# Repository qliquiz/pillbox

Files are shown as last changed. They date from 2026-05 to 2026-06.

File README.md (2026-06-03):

# PillBox IoT 💊 — Умная таблетница на базе ESP32-C3

Инновационное IoT-устройство для контроля регулярности приема лекарств. Таблетница автоматически напоминает о
необходимости приема звуковым сигналом, отправляет уведомления в Telegram и позволяет удаленно настраивать расписание
через чат-бота.

Проект разработан с учетом сетевых ограничений (работает в РФ без VPN через Google-прокси шлюз), но основные функции
напоминания теперь не зависят от интернета: время хранится в RTC-модуле DS1302. Текущая версия рассчитана на работу
от кабельного питания; аккумулятор и зарядный модуль описаны как аппаратный задел для следующего этапа.

---

## 🚀 Основные возможности

* **Локальная настройка (Captive Portal):** При первом запуске устройство создает собственную Wi-Fi сеть
  `PillBox_Setup`. Настройка параметров Wi-Fi, Chat ID, текущего времени RTC и расписания происходит в локальном
  веб-интерфейсе.
* **Автономное время:** Модуль DS1302 с батарейкой CR2032 хранит реальное время без запросов к NTP и продолжает идти
  при отключении основного питания.
* **Уведомления в Telegram:** Устройство присылает сообщение `🔔 ВРЕМЯ ПИТЬ ТАБЛЕТКИ!`, а также отчет
  `✅ Таблетки приняты`, когда вы открываете крышку. Уведомления отправляются при доступном Wi-Fi.
* **Удаленное управление:** Возможность менять время будильников прямо из чата Telegram с помощью команд `/t1 HH:MM` и
  `/t2 HH:MM`, а также корректировать RTC командой `/time YYYY-MM-DD HH:MM`.
* **Звуковой сигнал:** Пищалка подключена к `GPIO 5` и `GND`; прошивка генерирует звуковой тон функцией `tone()`, поэтому
  сигнал звучит как писк, а не как одиночные щелчки.
* **Энергонезависимая память:** Все настройки (Wi-Fi, будильники, Chat ID) сохраняются во встроенную память ESP32 (
  `Preferences`) и не стираются при отключении питания.
* **Питание:** Текущая прошивка рассчитана на стабильную работу от кабельного питания. Батарея и TP4056 будут
  использоваться для автономности на следующем этапе.
* **Мгновенный сброс:** Физический датчик на крышке мгновенно отключает пищалку при открытии, не дожидаясь окончания
  отправки сетевых запросов.

---

## 🔌 Схема подключения (Hardware)

Устройство спроектировано на базе микроконтроллера **ESP32-C3 Mini**.

| Компонент | Пин на ESP32-C3 | Описание подключения |
|:---|:---|:---|
| **Датчик крышки (кнопка)** | `GPIO 0` | Один контакт кнопки к `GPIO 0`, второй к `GND`. В прошивке включена внутренняя подтяжка `INPUT_PULLUP`. |
| **DS1302 RST / CE** | `GPIO 1` | Линия сброса/выбора RTC-модуля. |
| **Измерение батареи / зарядки** | `GPIO 2` | Зарезервировано для следующего этапа. В текущей прошивке не используется. |
| **DS1302 DAT / IO** | `GPIO 3` | Двунаправленная линия данных RTC-модуля. |
| **DS1302 CLK / SCLK** | `GPIO 4` | Тактовая линия RTC-модуля. |
| **Пищалка / звуковой излучатель** | `GPIO 5`, `GND` | Один контакт к `GPIO 5`, второй к `GND`. Прошивка генерирует тон 2500 Гц через `tone()`. Для громкого 5 В излучателя лучше использовать транзисторный ключ. |
| **DS1302 питание** | `3.3V`, `GND` | Основное питание RTC от ESP32, резервное питание от CR2032 на модуле часов. |
| **Зарядный модуль TP4056** | Питание | Аппаратный задел под автономность. Для текущей проверки от кабеля прошивка не использует сигналы зарядки или напряжение батареи. |

### Логика работы датчика крышки:

* **Крышка ЗАКРЫТА (кнопка нажата):** GPIO 0 замкнут на землю. На пине уровень **LOW (0)**.
* **Крышка ОТКРЫТА (кнопка отпущена):** Внутренняя подтяжка ESP32 удерживает пин в уровне **HIGH (1)**.

---

## 🛠 Инструкция по развертыванию (Setup Guide)

### Шаг 1: Подготовка Telegram-бота

1. Найдите в Telegram бота `@BotFather` и создайте нового бота с помощью команды `/newbot`. Скопируйте полученный *
   *Token**.
2. Найдите бота `@myidbot` и отправьте команду `/getid`, чтобы узнать ваш числовой **Chat ID**. Ник вида
   `@username` не подходит.
3. Отправьте вашему созданному боту команду `/start`, чтобы разрешить ему писать вам.

### Шаг 2: Настройка Google Apps Script (Прокси-шлюз)

Для стабильной отправки сообщений из РФ используется бесплатный веб-интерфейс Google в качестве моста:

1. Перейдите на [script.google.com](https://script.google.com/) и создайте новый проект.
2. Вставьте следующий код:
   ```javascript
   function doGet(e) {
     var token = e.parameter.token;
     var method = e.parameter.method || "sendMessage";
     var url = "https://api.telegram.org/bot" + token + "/" + method;
     
     var params = [];
     for (var p in e.parameter) {
       if (p !== 'token' && p !== 'method') {
         params.push(p + "=" + encodeURIComponent(e.parameter[p]));
       }
     }
     params.push("nocache=" + Math.random());
     if (params.length > 0) url += "?" + params.join("&");
     
     var response = UrlFetchApp.fetch(url, {muteHttpExceptions: true});
     return ContentService.createTextOutput(response.getContentText());
   }
   ```
3. Нажмите **«Начать развертывание»** -> **«Новое развертывание»**.
4. Выберите тип: **«Веб-приложение»**. Доступ: **«Все» (Anyone)**.
5. Скопируйте полученный URL (он понадобится для прошивки).

### Шаг 3: Настройка проекта в IDE (PlatformIO)

1. Откройте проект в CLion / VS Code с установленным плагином PlatformIO.
2. Приведите файл `platformio.ini` к следующему виду:
   ```ini
   [env:esp32-c3-devkitm-1]
   platform = espressif32
   board = esp32-c3-devkitm-1
   framework = arduino
   monitor_speed = 115200
   build_flags = 
       -D ARDUINO_USB_MODE=1
       -D ARDUINO_USB_CDC_ON_BOOT=1
   lib_deps = 
       bblanchon/ArduinoJson @ ^6.21.3
       makuna/RTC @ ^2.5.0
   ```
3. В файле `src/main.cpp` найдите блок констант и вставьте ваши данные:
   ```cpp
   const String BOT_TOKEN = "ВАШ_ТОКЕН_ОТ_BOTFATHER";
   const String G_SCRIPT_URL = "ВАШ_URL_ОТ_GOOGLE_SCRIPT";
   ```
4. Загрузите прошивку в плату.

---

## 📱 Первый запуск и настройка

1. Зайти в Телеграм-бота @IoTRegApiBot и нажать "Старт" (/start).
2. Подайте питание на таблетницу.
3. С телефона подключитесь к появившейся Wi-Fi сети `PillBox_Setup` (пароль не требуется).
4. В открывшемся окне авторизации (или перейдя по адресу `192.168.4.1`) введите:
    * **Имя Wi-Fi:** Название точки доступа вашего телефона (или домашнего роутера).
    * **Пароль Wi-Fi:** Пароль от этой сети.
    * **Chat ID:** Ваш числовой Telegram ID (полученный на Шаге 1, не ник).
    * **Текущее время:** Локальное время телефона для первичной настройки DS1302.
    * **Утро / Вечер:** Желаемое время напоминаний.
5. Нажмите **«Сохранить»**. Устройство запишет настройки и время в RTC, затем перезагрузится.
6. Если Wi-Fi доступен, устройство подключится к сети и пришлет в Telegram сообщение: `Таблетница в сети! 🟢`.
   Если сохраненная сеть недоступна, устройство поднимет `PillBox_Setup`, чтобы параметры можно было ввести заново.
   Будильники при этом продолжают проверяться по DS1302.

### Сброс сохраненных настроек

Если нужно заново открыть портал настройки и стереть сохраненные Wi-Fi, Chat ID и расписание, выполните:

```bash
/opt/homebrew/bin/pio run -t erase -e esp32-c3-devkitm-1
/opt/homebrew/bin/pio run -t upload -e esp32-c3-devkitm-1
```

Команда `erase` стирает Flash-память ESP32, но не сбрасывает DS1302: часы продолжают идти от своей батарейки CR2032.

---

## 🤖 Управление через Telegram

Вы можете отправлять боту следующие команды:

* `/status` — Возвращает текущее системное время таблетницы, расписание будильников и физическое состояние крышки (
  открыта/закрыта).
* `/t1 HH:MM` — Изменить время утреннего приема (например, `/t1 08:30`).
* `/t2 HH:MM` — Изменить время вечернего приема (например, `/t2 21:15`).
* `/time YYYY-MM-DD HH:MM` — Установить текущее время RTC (например, `/time 2026-06-01 21:30`).

---

## 🛠 Технологический стек

* **Платформа:** ESP32-C3 (RISC-V 32-bit CPU, Wi-Fi & Bluetooth).
* **Среда разработки:** CLion / VS Code + PlatformIO.
* **Фреймворк:** Arduino (C++).
* **Многозадачность:** FreeRTOS (управление пищалкой выделено в отдельную низкоуровневую задачу для стабильной работы
  звука).
* **Звук:** Arduino `tone()` на `GPIO 5`, частота сигнала 2500 Гц.
* **RTC:** DS1302 с резервной батарейкой CR2032.
* **Питание:** Кабельное питание. Аккумулятор и зарядный модуль TP4056 подготовлены для следующего этапа.
* **Сетевые протоколы:** HTTPS, DNS (для Captive Portal).
* **Облачные технологии:** Google Apps Script (проксирование трафика).

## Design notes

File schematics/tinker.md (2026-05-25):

# Tinkercad
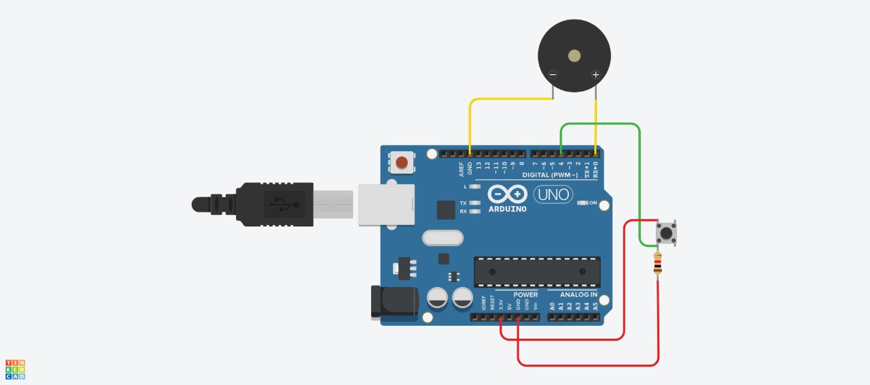
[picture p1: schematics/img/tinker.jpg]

🔗 [Ссылка](https://www.tinkercad.com/things/cp1gPXaVb1g-powerful-kup-jaagub)

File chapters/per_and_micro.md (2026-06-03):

### Раздел 2. Способы взаимодействия периферийного оборудования и микроконтроллера

В разработанном устройстве реализовано три уровня взаимодействия:
локальное (физическое подключение датчиков и актуаторов к портам ввода-вывода микроконтроллера)
аппаратное хранение времени и сетевое (передача данных через беспроводные интерфейсы).

#### 2.1. Локальное взаимодействие с периферией

Для контроля состояния устройства и генерации оповещений используются дискретные цифровые
каналы ввода-вывода общего назначения (GPIO) микроконтроллера ESP32-C3.

1. **Цифровой вход — Датчик положения крышки (GPIO 0)**
   Для опроса состояния крышки используется кнопка, подключенная между портом GPIO 0 и землей (GND).
   В программе включена внутренняя подтяжка `INPUT_PULLUP`.
    * При закрытой крышке кнопка нажата, цепь замкнута на землю, и на входе микроконтроллера фиксируется
      низкий логический уровень (`LOW`).
    * При открытии крышки цепь размыкается, и внутренняя подтяжка удерживает вывод в высоком уровне (`HIGH`).
      Данный переход обрабатывается управляющей программой как сигнал к отключению будильника.

2. **Цифровой выход — звуковой излучатель (GPIO 5)**
   Для звукового оповещения используется пищалка, подключенная между GPIO 5 и общей землей (GND).
   Управляющая программа генерирует на выводе звуковой сигнал частотой 2500 Гц с помощью функции `tone()`.
   Такой режим подходит для пассивного излучателя и дает более выраженный писк, чем простое включение уровня `HIGH`.
   Если требуется питание излучателя от линии 5 В или большая громкость, рекомендуется использовать транзисторный ключ,
   чтобы не перегружать вывод ESP32-C3.

3. **Часы реального времени DS1302**
   Для автономного подсчета времени используется RTC-модуль DS1302 с резервной батарейкой CR2032.
   Модуль подключается к ESP32-C3 по трехпроводному интерфейсу:
    * `RST` / `CE` -> GPIO 1;
    * `DAT` / `IO` -> GPIO 3;
    * `CLK` / `SCLK` -> GPIO 4;
    * `VCC` -> 3.3 В, `GND` -> общая земля.
      После первичной настройки модуль продолжает хранить текущее время независимо от Wi-Fi и основного питания.

4. **Резервный вход питания (GPIO 2)**
   GPIO 2 зарезервирован для следующего этапа — измерения напряжения батареи или состояния зарядки.
   В текущей прошивке этот вход не используется.

5. **Зарядный модуль TP4056**
   Зарядный модуль и аккумулятор рассматриваются как аппаратный задел под автономность. На текущем этапе устройство
   проверяется от кабельного питания, а прошивка не рассчитывает заряд и не принимает решений по состоянию батареи.

6. **Проводной интерфейс UART**
   Обмен данными между микроконтроллером и персональным компьютером на этапе разработки,
   прошивки и отладки осуществляется по последовательному интерфейсу UART через встроенный
   в чип ESP32-C3 аппаратный USB-CDC конвертер.

#### 2.2. Сетевое взаимодействие и протоколы связи

Сетевая часть устройства построена на базе встроенного приемопередатчика
Wi-Fi и стека протоколов TCP/IP.

1. **Режимы работы Wi-Fi:**
    * **Режим AP (Точка доступа):** Активируется при первом запуске или отсутствии сохраненных сетевых настроек.
      Микроконтроллер создает локальную сеть `PillBox_Setup` для подключения смартфона пользователя.
    * **Режим STA (Клиент):** Рабочий режим, в котором устройство подключается к беспроводной точке
      доступа для выхода в глобальную сеть Интернет.
    * **Режим повторной настройки:** Если сохраненная сеть временно недоступна, устройство не стирает настройки
      автоматически, а поднимает `PillBox_Setup`, чтобы пользователь мог изменить Wi-Fi, Chat ID и расписание.
      Проверка расписания по DS1302 при этом продолжает выполняться.

2. **Протоколы прикладного уровня:**
    * **HTTP:** Используется в режиме точки доступа. На микроконтроллере развернут легковесный веб-сервер,
      который отдает конфигурационную HTML-страницу пользователю и принимает новые параметры расписания и сети через
      GET-запросы (`/save?s=...&p=...`).
    * **DNS:** Задействован в режиме настройки для реализации технологии Captive Portal.
      Локальный DNS-сервер перехватывает все системные запросы подключившегося смартфона и принудительно перенаправляет
      их на веб-интерфейс таблетницы (`192.168.4.1`), вызывая автоматическое появление окна настройки на экране
      телефона.
    * **HTTPS:** Применяется для безопасной отправки уведомлений и получения команд.
      Поскольку прямое обращение к серверам Telegram API (`api.telegram.org`) с микроконтроллеров на территории
      РФ заблокировано или нестабильно, запросы отправляются методом GET по защищенному каналу на облачный прокси-сервер
      Google Apps Script,
      находящийся вне зоны ограничений, который выступает шлюзом для ретрансляции данных в Telegram.

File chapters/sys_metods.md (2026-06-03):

### Раздел 3. Способы взаимодействия модулей системы

Разработанная система представляет собой распределенный аппаратно-программный комплекс,
состоящий из шести основных взаимодействующих модулей:

1. **Аппаратный модуль (микроконтроллер ESP32-C3)** — конечное устройство с датчиками.
2. **Пользовательское устройство (смартфон)** — средство локальной настройки и отображения интерфейса.
3. **Модуль часов реального времени DS1302** — автономный источник текущего времени.
4. **Подсистема питания** — на текущем этапе работа от кабельного питания; аккумулятор и TP4056 подготовлены для
   следующего этапа.
5. **Облачный прокси-сервер (Google Apps Script)** — шлюз для обхода сетевых ограничений.
6. **Сервер обмена сообщениями (Telegram Bot API)** — среда удаленного управления и оповещения.

Взаимодействие между данными модулями построено на базе различных программных интерфейсов и протоколов передачи данных.
Архитектуру взаимодействия можно разделить на три ключевых сценария.

#### 3.1. Локальное взаимодействие: Смартфон ↔ ESP32-C3 (Этап настройки)

На этапе первоначальной конфигурации при отсутствии подключения к сети Интернет
взаимодействие модулей осуществляется напрямую без участия сторонних серверов.

* **Используемый интерфейс:** Локальный HTTP API.
* **Механизм взаимодействия:**
  Смартфон пользователя подключается к Wi-Fi сети микроконтроллера.
  При попытке любого сетевого запроса срабатывает встроенный DNS-перехватчик,
  перенаправляющий пользователя на веб-страницу настройки, хранящуюся в постоянной памяти ESP32-C3.
  Передача параметров осуществляется посредством отправки асинхронного HTTP-запроса методом `GET`
  с параметрами в строке запроса:
  `GET /save?s=[SSID]&p=[password]&c=[Chat_ID]&dt=[YYYY-MM-DDTHH:MM]&t1=[HH:MM]&t2=[HH:MM]`
  Микроконтроллер парсит строку запроса, сохраняет полученные данные в энергонезависимую память
  записывает текущее время в DS1302 и выполняет перезагрузку для перехода в рабочий режим.

#### 3.2. Локальное аппаратное взаимодействие: ESP32-C3 ↔ DS1302

Для проверки расписания таблетница использует аппаратные часы реального времени DS1302.

* **Используемый интерфейс:** Трехпроводной последовательный интерфейс DS1302.
* **Механизм взаимодействия:**
  Микроконтроллер обращается к DS1302 по линиям `RST`, `DAT` и `CLK`, считывает текущие часы и минуты
  и сравнивает их с сохраненным расписанием. Благодаря резервной батарейке CR2032 часы продолжают идти без
  подключения к интернету и без основного питания устройства.

#### 3.3. Исходящее взаимодействие: ESP32-C3 → Google Cloud → Telegram

Для отправки уведомлений конечное устройство должно передать данные на серверы Telegram.
Из-за блокировок прямого доступа к API Telegram на территории РФ используется промежуточный облачный шлюз.

* **Используемый интерфейс:** Web API с проксированием.
* **Механизм взаимодействия:**
  ESP32-C3 формирует защищенное HTTPS-соединение с сервером Google Apps Script,
  передавая параметры сообщения в зашифрованном GET-запросе:
  `GET /macros/s/[Script_ID]/exec?token=[Bot_Token]&method=sendMessage&chat_id=[Chat_ID]&text=[Message]`
  Облачный скрипт Google принимает этот запрос, декодирует параметры и инициирует
  внутренний запрос со стороны серверов Google к официальному серверу Telegram:
  `POST https://api.telegram.org/bot[Bot_Token]/sendMessage`
  Telegram доставляет push-уведомление на смартфон пользователя в чат-бот.

#### 3.4. Входящее взаимодействие: Смартфон → Telegram → Google Cloud → ESP32-C3

Для удаленного изменения времени будильников, корректировки RTC или запроса статуса устройства пользователь
отправляет текстовые команды в чат-бот на своем смартфоне.

* **Используемый интерфейс:** Web API Telegram.
* **Механизм взаимодействия:**
    1. Команда пользователя поступает на серверы Telegram и сохраняется в очереди сообщений бота.
    2. Микроконтроллер ESP32-C3, находясь в рабочем режиме, каждые 7 секунд отправляет через Google-шлюз запрос на
       получение обновлений:
       `GET /exec?token=[Bot_Token]&method=getUpdates&offset=[Last_Update_ID+1]`
    3. Google-шлюз транслирует этот запрос в Telegram, получает массив новых сообщений в формате JSON и пересылает его
       обратно на ESP32-C3.
    4. Микроконтроллер разбирает полученный JSON-пакет с помощью библиотеки `ArduinoJson`.
       Если ID отправителя совпадает с сохраненным в памяти `Chat_ID`, устройство извлекает текст команды.
       Команды `/t1` и `/t2` обновляют расписание в оперативной памяти и Flash-памяти, команда `/time`
       записывает текущее время в DS1302, а команда `/status` возвращает текущее состояние часов и крышки.
       Для корректной доставки кириллицы и служебных символов текст Telegram-сообщений URL-кодируется перед отправкой
       на Google Apps Script.

#### 3.5. Питание и режим без Wi-Fi

На текущем этапе устройство проверяется от кабельного питания. При недоступном Wi-Fi прошивка поднимает локальный портал
`PillBox_Setup` для повторной настройки, а проверка расписания продолжает работать от DS1302. Аккумулятор и TP4056
будут задействованы в прошивке на следующем этапе.

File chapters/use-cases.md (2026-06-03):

### Раздел 7. Сценарии использования и реакция устройства

Для описания взаимодействия пользователя с умной таблетницей разработаны
три основных сценария использования. В каждом сценарии предусмотрена визуальная,
звуковая или текстовая обратная связь от устройства, чтобы пользователь был уверен в правильности своих действий.

#### 7.1. Сценарий 1: Первоначальная настройка устройства

* **Действующее лицо:** Пользователь.
* **Предусловие:** Таблетница включена впервые от кабельного питания. В памяти устройства отсутствуют
  данные Wi-Fi и требуется первичная установка времени RTC.
  Пользователь нажал /start в @IoTRegApiBot
* **Основной сценарий взаимодействия:**
    1. Пользователь включает устройство от кабельного питания.
    2. Пользователь открывает настройки Wi-Fi на своем смартфоне и видит новую точку доступа с именем `PillBox_Setup`.
    3. Пользователь подключается к этой сети. На экране смартфона автоматически всплывает окно настройки с полями ввода.
    4. Пользователь заполняет поля: имя и пароль Wi-Fi, свой числовой Telegram Chat ID, текущее время и желаемое время
       приемов.
    5. Пользователь нажимает кнопку **«СОХРАНИТЬ»** на веб-странице.
* **Реакция устройства:**
    * После нажатия кнопки веб-интерфейс отображает надпись **«Готово!»**.
    * Через 2 секунды устройство выполняет автоматическую перезагрузку.
    * Устройство записывает текущее время в DS1302, сохраняет настройки и перезагружается.
    * При успешном подключении к мобильному хотспоту устройство отправляет пользователю в Telegram приветственное
      сообщение: **«Таблетница в сети! 🟢»**.
    * Если сохраненная сеть временно недоступна, устройство поднимает `PillBox_Setup` для повторной настройки.
      Будильники при этом продолжают работать по DS1302, но Telegram-уведомления и команды недоступны до восстановления
      Wi-Fi.

#### 7.2. Сценарий 2: Срабатывание будильника и прием лекарств

* **Действующее лицо:** Пользователь.
* **Предусловие:** Время на DS1302 настроено, расписание сохранено,
  крышка таблетницы закрыта.
* **Основной сценарий взаимодействия:**
    1. Внутреннее время таблетницы совпадает с временем будильника.
    2. Устройство начинает генерировать сигнал тревоги.
    3. Пользователь подходит к устройству, открывает общую крышку таблетницы, берет необходимый пенал с лекарствами и
       закрывает крышку обратно.
* **Реакция устройства:**
    * **В момент срабатывания:** Пищалка на GPIO 5 начинает издавать прерывистый тон. Если Wi-Fi доступен, в Telegram
      пользователю приходит push-уведомление: **«🔔 ВРЕМЯ ПИТЬ ТАБЛЕТКИ!»**.
    * **В момент открытия крышки:** Как только крышка приоткрывается, датчик фиксирует уровень `HIGH`, и зуммер
      мгновенно
      замолкает.
    * **После открытия:** При доступном Wi-Fi в Telegram приходит подтверждающее сообщение:
      **«✅ Таблетки приняты.»**.

#### 7.3. Сценарий 3: Удаленное управление и мониторинг

* **Действующее лицо:** Пользователь.
* **Предусловие:** Устройство находится в рабочем режиме и подключено к мобильной точке доступа.
* **Основной сценарий взаимодействия:**
    1. Пользователь, находясь вне дома, открывает чат-бот таблетницы в Telegram.
    2. Пользователь отправляет команду для изменения расписания (например, `/t1 09:30`), команду установки RTC
       (`/time 2026-06-01 21:30`) или команду запроса текущего состояния (`/status`).
* **Реакция устройства:**
    * При получении команды настройки времени (`/t1` или `/t2`) устройство обрабатывает запрос, сохраняет его в память
      NVS и отправляет ответное сообщение: **«✅ Утро установлено: 09:30»**.
    * При получении команды `/time` устройство записывает новое текущее время в DS1302.
    * При получении команды `/status` устройство мгновенно опрашивает свои датчики и RTC-модуль и присылает
      подробную сводку:
        * `📊 СТАТУС:`
        * `🕒 RTC: 2026-06-01 13:45:35` (позволяет пользователю убедиться, что часы идут верно).
        * `🌅 Утро: 09:30`
        * `🌌 Вечер: 20:00`
        * `📦 Крышка: ЗАКРЫТА` (позволяет удаленно проверить, не забыли ли закрыть таблетницу дома).

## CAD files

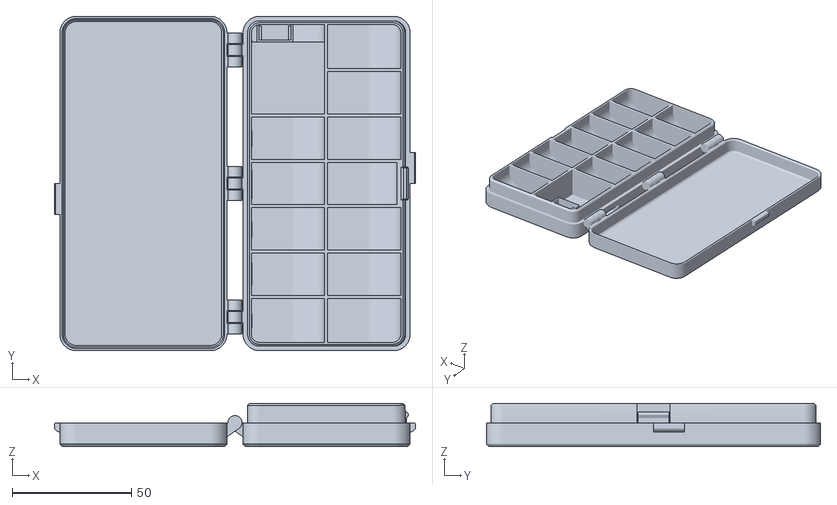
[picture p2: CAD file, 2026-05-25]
3d_models/pillbox.stl
151.1 x 140.0 x 18.0

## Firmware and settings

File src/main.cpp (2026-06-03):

#include <Arduino.h>
#include <ArduinoJson.h>
#include <DNSServer.h>
#include <HTTPClient.h>
#include <Preferences.h>
#include <RtcDS1302.h>
#include <ThreeWire.h>
#include <WebServer.h>
#include <WiFi.h>
#include <WiFiClientSecure.h>


const String BOT_TOKEN = "";
const String G_SCRIPT_URL = "";

constexpr int LID_SENSOR_PIN = 0;
constexpr int RTC_RST_PIN = 1;
constexpr int RTC_DAT_PIN = 3;
constexpr int RTC_CLK_PIN = 4;
constexpr int BUZZER_PIN = 5;
constexpr int BUZZER_TONE_HZ = 2500;
constexpr unsigned long WIFI_RETRY_INTERVAL_MS = 5UL * 60UL * 1000UL;
constexpr unsigned long WIFI_RETRY_TIMEOUT_MS = 15000UL;

String ssid, pass, chatId, alarm1, alarm2;
String lastTriggeredMinute = "";
bool wifiReconnectInProgress = false;
volatile bool isAlerting = false;
unsigned long lastWiFiRetry = 0;
unsigned long wifiRetryStartedAt = 0;
long lastUpdateId = 0; // ID последнего обработанного сообщения из Telegram

ThreeWire rtcWire(RTC_DAT_PIN, RTC_CLK_PIN, RTC_RST_PIN); // DS1302: DAT/IO, CLK/SCLK, RST/CE
RtcDS1302<ThreeWire> rtc(rtcWire);
Preferences prefs; // объект для работы с энергонезависимой памятью (Flash)
DNSServer dnsServer; // DNS-сервер для перехвата запросов (Captive Portal)
WebServer server(80); // локальный веб-сервер для настройки таблетницы по Wi-Fi
QueueHandle_t msgQueue; // очередь для безопасной передачи сообщений между задачами

// ======================= ВРЕМЯ И ДАТЧИКИ =======================

bool isLidClosed()
{
	// Кнопка крышки замыкает GPIO0 на GND, поэтому используем INPUT_PULLUP.
	return digitalRead(LID_SENSOR_PIN) == LOW;
}

String twoDigits(const uint8_t value)
{
	if (value < 10) return "0" + String(value);
	return String(value);
}

String formatRtcTime(const RtcDateTime &dt)
{
	return twoDigits(dt.Hour()) + ":" + twoDigits(dt.Minute());
}

String formatRtcDateTime(const RtcDateTime &dt)
{
	if (!dt.IsValid() || dt.Year() < 2024) return "не настроено";

	return String(dt.Year()) + "-" + twoDigits(dt.Month()) + "-" + twoDigits(dt.Day()) + " " +
	       twoDigits(dt.Hour()) + ":" + twoDigits(dt.Minute()) + ":" + twoDigits(dt.Second());
}

bool parseDateTime(const String &value, RtcDateTime &result)
{
	if (value.length() < 16) return false;
	if (value.charAt(4) != '-' || value.charAt(7) != '-' || value.charAt(13) != ':') return false;

	const char separator = value.charAt(10);
	if (separator != 'T' && separator != ' ') return false;

	const uint16_t year = value.substring(0, 4).toInt();
	const uint8_t month = value.substring(5, 7).toInt();
	const uint8_t day = value.substring(8, 10).toInt();
	const uint8_t hour = value.substring(11, 13).toInt();
	const uint8_t minute = value.substring(14, 16).toInt();

	if (year < 2024 || month < 1 || month > 12 || day < 1 || day > 31 || hour > 23 || minute > 59)
	{
		return false;
	}

	result = RtcDateTime(year, month, day, hour, minute, 0);
	return result.IsValid();
}

bool isValidAlarmTime(const String &value)
{
	if (value.length() != 5 || value.charAt(2) != ':') return false;
	const int hour = value.substring(0, 2).toInt();
	const int minute = value.substring(3, 5).toInt();
	return hour >= 0 && hour <= 23 && minute >= 0 && minute <= 59;
}

void setRtcDateTime(const RtcDateTime &dt)
{
	if (rtc.GetIsWriteProtected()) rtc.SetIsWriteProtected(false);
	if (!rtc.GetIsRunning()) rtc.SetIsRunning(true);
	rtc.SetDateTime(dt);
}

// ======================= TELEGRAM =======================

String urlEncode(const String &value)
{
	String encoded = "";
	for (size_t i = 0; i < value.length(); i++)
	{
		const auto c = static_cast<uint8_t>(value.charAt(i));
		if ((c >= 'A' && c <= 'Z') || (c >= 'a' && c <= 'z') || (c >= '0' && c <= '9') ||
		    c == '-' || c == '_' || c == '.' || c == '~')
		{
			encoded += static_cast<char>(c);
		}
		else if (c == ' ')
		{
			encoded += "%20";
		}
		else
		{
			const auto hex = "0123456789ABCDEF";
			encoded += '%';
			encoded += hex[c >> 4];
			encoded += hex[c & 0x0F];
		}
	}
	return encoded;
}

// Функция для добавления сообщения в очередь на отправку (не блокирует процессор)
void sendMsg(const String &text)
{
	// Выделяем память под строку и копируем её, чтобы данные не пропали, пока задача их не заберет
	char *msg = strdup(text.c_str());
	// Пытаемся отправить указатель на строку в очередь без ожидания (0 миллисекунд)
	if (xQueueSend(msgQueue, &msg, 0) != pdPASS)
	{
		free(msg); // если очередь переполнена, удаляем сообщение, чтобы не засорять память
	}
}

void startWiFiReconnect()
{
	if (ssid == "" || WiFiClass::getMode() == WIFI_AP) return;

	WiFiClass::mode(WIFI_STA);
	WiFi.begin(ssid.c_str(), pass.c_str());
	wifiReconnectInProgress = true;
	wifiRetryStartedAt = millis();
	lastWiFiRetry = millis();
	Serial.println("Пробуем восстановить WiFi.");
}

void serviceWiFiReconnect()
{
	if (WiFiClass::getMode() == WIFI_AP || ssid == "") return;

	if (WiFiClass::status() == WL_CONNECTED)
	{
		if (wifiReconnectInProgress)
		{
			wifiReconnectInProgress = false;
			sendMsg("Таблетница снова в сети! 🟢");
		}
		return;
	}

	if (wifiReconnectInProgress)
	{
		if (millis() - wifiRetryStartedAt > WIFI_RETRY_TIMEOUT_MS)
		{
			wifiReconnectInProgress = false;
			WiFi.disconnect(true);
			WiFiClass::mode(WIFI_OFF);
			Serial.println("WiFi не найден, остаемся в автономном режиме.");
		}
		return;
	}

	if (millis() - lastWiFiRetry > WIFI_RETRY_INTERVAL_MS)
	{
		startWiFiReconnect();
	}
}

// Функция для отправки любых запросов в Telegram через Google-прокси
String callTelegram(const String &method, const String &params)
{
	if (WiFiClass::status() != WL_CONNECTED)
	{
		Serial.println("Telegram skipped: WiFi is not connected.");
		return "";
	}
	if (BOT_TOKEN == "" || G_SCRIPT_URL == "")
	{
		Serial.println("Telegram skipped: BOT_TOKEN or G_SCRIPT_URL is empty.");
		return "";
	}

	WiFiClientSecure client;
	client.setInsecure(); // отключаем строгую проверку SSL-сертификатов Google (экономит память)

	HTTPClient http;
	String url = G_SCRIPT_URL + "?token=" + BOT_TOKEN + "&method=" + method + "&" + params;

	// Настраиваем правила HTTP-клиента
	http.setFollowRedirects(HTTPC_STRICT_FOLLOW_REDIRECTS);
	// Google всегда делает редирект, мы обязаны следовать за ним
	http.setTimeout(15000); // таймаут ожидания ответа от Google — 15 секунд

	String response = "";
	if (http.begin(client, url))
	{
		const int httpCode = http.GET();
		Serial.print("Telegram ");
		Serial.print(method);
		Serial.print(" HTTP ");
		Serial.println(httpCode);
		if (httpCode == 200) response = http.getString();
		if (response != "")
		{
			Serial.print("Telegram response: ");
			Serial.println(response.substring(0, 180));
		}
		http.end();
	}
	else
	{
		Serial.println("Telegram HTTP begin failed.");
	}
	return response;
}

// Фоновая задача отправки сообщений
[[noreturn]] void telegramTask(void *pvParameters)
{
	char *msgText;
	for (;;)
	{
		// Ждем появления сообщения в очереди. Если очередь пуста, задача "засыпает" и не тратит ресурсы процессора
		if (xQueueReceive(msgQueue, &msgText, portMAX_DELAY) == pdPASS)
		{
			if (chatId == "")
			{
				Serial.println("Telegram send skipped: Chat ID is empty.");
			}
			else
			{
				callTelegram("sendMessage", "chat_id=" + chatId + "&text=" + urlEncode(String(msgText)));
			}
			free(msgText); // освобождаем динамическую память, выделенную под текст
		}
	}
}

// Функция разбора входящих сообщений и команд из Telegram
void checkBot()
{
	String json = callTelegram("getUpdates", "offset=" + String(lastUpdateId + 1));
	if (json == "" || json.length() < 10) return;

	DynamicJsonDocument doc(2048); // создаем буфер для разбора JSON
	if (deserializeJson(doc, json)) return;

	const JsonArray results = doc["result"].as<JsonArray>();
	for (JsonObject result: results)
	{
		lastUpdateId = result["update_id"];

		auto text = result["message"]["text"].as<String>();
		auto fromId = result["message"]["chat"]["id"].as<String>();
		fromId.trim();
		chatId.trim();

		if (fromId == chatId)
		{
			if (text.startsWith("/t1 "))
			{
				const String newAlarm = text.substring(4, 9);
				if (isValidAlarmTime(newAlarm))
				{
					alarm1 = newAlarm;
					sendMsg("✅ Утро: " + alarm1);
				}
				else
				{
					sendMsg("⚠️ Формат: /t1 HH:MM");
				}
			}
			else if (text.startsWith("/t2 "))
			{
				const String newAlarm = text.substring(4, 9);
				if (isValidAlarmTime(newAlarm))
				{
					alarm2 = newAlarm;
					sendMsg("✅ Вечер: " + alarm2);
				}
				else
				{
					sendMsg("⚠️ Формат: /t2 HH:MM");
				}
			}
			else if (text.startsWith("/time "))
			{
				RtcDateTime newTime;
				if (parseDateTime(text.substring(6), newTime))
				{
					setRtcDateTime(newTime);
					sendMsg("✅ Время RTC: " + formatRtcDateTime(newTime));
				}
				else
				{
					sendMsg("⚠️ Формат: /time YYYY-MM-DD HH:MM");
				}
			}
			else if (text == "/status")
			{
				const RtcDateTime now = rtc.GetDateTime();
				String lid = isLidClosed() ? "ЗАКРЫТА" : "ОТКРЫТА";
				sendMsg(
					"📊 СТАТУС:\n🕒 RTC: " + formatRtcDateTime(now) + "\n🌅 Утро: " + alarm1 +
					"\n🌌 Вечер: " + alarm2 + "\n📦 Крышка: " + lid
				);
			}
			// Сохраняем новые будильники во Flash-память ESP32
			prefs.begin("pillbox", false);
			prefs.putString("t1", alarm1);
			prefs.putString("t2", alarm2);
			prefs.end();
		}
	}
}

// Фоновая задача для регулярного опроса Telegram
[[noreturn]] void botPollTask(void *pvParameters)
{
	for (;;)
	{
		if (WiFiClass::status() == WL_CONNECTED && WiFiClass::getMode() == WIFI_STA)
		{
			checkBot();
		}
		vTaskDelay(7000 / portTICK_PERIOD_MS); // спим ровно 7 секунд без задержки основного ядра
	}
}

// ======================= РАБОТА С ЖЕЛЕЗОМ =======================

void buzzerOn()
{
	tone(BUZZER_PIN, BUZZER_TONE_HZ);
}

void buzzerOff()
{
	noTone(BUZZER_PIN);
	digitalWrite(BUZZER_PIN, LOW);
}

// Фоновая задача для пищалки (приоритет 3)
[[noreturn]] void buzzerTask(void *pvParameters)
{
	for (;;)
	{
		if (isAlerting)
		{
			// ФАЗА ЗВУКА: пищим 300 мс, но проверяем флаг крышки каждые 10 мс для мгновенного сброса
			for (int i = 0; i < 30; i++)
			{
				if (!isAlerting) break; // если крышку открыли, мгновенно прерываем писк
				buzzerOn();
				vTaskDelay(10 / portTICK_PERIOD_MS);
			}
			buzzerOff();

			// ФАЗА ТИШИНЫ: ждем 800 мс, также регулярно опрашивая флаг крышки
			for (int i = 0; i < 80; i++)
			{
				if (!isAlerting) break;
				vTaskDelay(10 / portTICK_PERIOD_MS);
			}
		}
		else
		{
			// Если тревоги нет, гарантируем, что пищалка выключена, и "спим"
			buzzerOff();
			vTaskDelay(50 / portTICK_PERIOD_MS);
		}
	}
}

// HTML-сайт настройки (хранится в Flash-памяти программ PROGMEM)
constexpr char INDEX_HTML[] PROGMEM = R"=====(
<!DOCTYPE html><html><head><meta charset="utf-8"><meta name="viewport" content="width=device-width, initial-scale=1.0">
<style>body{font-family:sans-serif;background:#f4f4f9;padding:20px;display:flex;flex-direction:column;align-items:center;}
.card{background:white;padding:25px;border-radius:15px;box-shadow:0 4px 10px rgba(0,0,0,0.1);width:100%;max-width:320px;}
input{width:100%;padding:12px;margin-top:10px;border:1px solid #ddd;border-radius:8px;box-sizing:border-box;font-size:16px;}
button{width:100%;background:#4CAF50;color:white;border:none;padding:15px;border-radius:8px;margin-top:20px;width:100%;}</style></head>
<body><div class="card"><h2>PillBox Setup 💊</h2>
<input id="s" placeholder="Имя WiFi сети"><input type="password" id="p" placeholder="Пароль WiFi"><input id="c" placeholder="Chat ID">
<label>Текущее время:</label><input type="datetime-local" id="dt">
<label>Утро:</label><input type="time" id="t1" value="08:00"><label>Вечер:</label><input type="time" id="t2" value="20:00">
<button onclick="save()">СОХРАНИТЬ</button></div>
<script>
function pad(n){return String(n).padStart(2,'0')}
const d=new Date();document.getElementById('dt').value=`${d.getFullYear()}-${pad(d.getMonth()+1)}-${pad(d.getDate())}T${pad(d.getHours())}:${pad(d.getMinutes())}`;
function save(){
const q=new URLSearchParams({s:document.getElementById('s').value,p:document.getElementById('p').value,c:document.getElementById('c').value,dt:document.getElementById('dt').value,t1:document.getElementById('t1').value,t2:document.getElementById('t2').value});
fetch('/save?'+q.toString()).then(()=>alert("Настройки сохранены! Перезагрузка..."));
}</script></body></html>
)=====";

// Обработчик сохранения данных, прилетевших с веб-страницы телефона
void handleSave()
{
	prefs.begin("pillbox", false); // открываем память во Flash для записи
	prefs.putString("s", server.arg("s"));
	prefs.putString("p", server.arg("p"));
	prefs.putString("c", server.arg("c"));
	prefs.putString("t1", server.arg("t1"));
	prefs.putString("t2", server.arg("t2"));
	prefs.end();

	RtcDateTime setupTime;
	if (parseDateTime(server.arg("dt"), setupTime))
	{
		setRtcDateTime(setupTime);
	}

	server.send(200, "text/plain", "OK");
	delay(2000);
	ESP.restart(); // применяем
}

void startSetupPortal()
{
	WiFiClass::mode(WIFI_AP);
	WiFi.softAP("PillBox_Setup");
	dnsServer.start(53, "*", WiFi.softAPIP());
	server.on("/", []() {
		server.send(200, "text/html", INDEX_HTML);
	});
	server.on("/save", handleSave);
	server.onNotFound([]() {
		server.sendHeader("Location", "/", true);
		server.send(302, "text/plain", "");
	});
	server.begin();

	Serial.print("Setup portal started: ");
	Serial.println(WiFi.softAPIP());
}

void printDebugStatus(const RtcDateTime &now)
{
	Serial.print("RTC=");
	Serial.print(formatRtcDateTime(now));
	Serial.print(" alarm1=");
	Serial.print(alarm1);
	Serial.print(" alarm2=");
	Serial.print(alarm2);
	Serial.print(" lid=");
	Serial.print(isLidClosed() ? "CLOSED" : "OPEN");
	Serial.print(" alert=");
	Serial.print(isAlerting ? "YES" : "NO");
	Serial.print(" wifi=");
	Serial.println(WiFiClass::status() == WL_CONNECTED ? "CONNECTED" : "OFFLINE");
}

void serviceAlarm()
{
	static unsigned long lastCheck = 0;
	static unsigned long lastDebug = 0;

	if (millis() - lastCheck <= 1000) return;
	lastCheck = millis();

	const RtcDateTime now = rtc.GetDateTime();
	if (millis() - lastDebug > 5000)
	{
		lastDebug = millis();
		printDebugStatus(now);
	}

	if (!now.IsValid() || now.Year() < 2024)
	{
		return;
	}

	const String cur = formatRtcTime(now);
	if ((cur == alarm1 || cur == alarm2) && cur != lastTriggeredMinute)
	{
		if (isLidClosed())
		{
			isAlerting = true;
			lastTriggeredMinute = cur;
			Serial.print("Alarm triggered at ");
			Serial.println(cur);
			sendMsg("🔔 ВРЕМЯ ПИТЬ ТАБЛЕТКИ!");
		}
		else
		{
			Serial.print("Alarm matched at ");
			Serial.print(cur);
			Serial.println(", but lid is open.");
		}
	}
}

void serviceLidReset()
{
	if (!isAlerting || isLidClosed()) return;

	isAlerting = false; // сбрасываем флаг тревоги (остановит buzzerTask)
	buzzerOff(); // на всякий случай выключаем пищалку физически
	Serial.println("Крышка открыта - сброс звука!");

	// Даем 100 мс задержки, чтобы задача buzzerTask успела увидеть изменения
	// и завершила работу, пока Wi-Fi модуль не занял процессор отправкой сообщения
	vTaskDelay(100 / portTICK_PERIOD_MS);

	sendMsg("✅ Таблетки приняты."); // кладем сообщение в очередь на отправку
}

// ======================= ИНИЦИАЛИЗАЦИЯ И ОСНОВНОЙ ЦИКЛ =======================

void setup()
{
	Serial.begin(115200);
	delay(1000);
	Serial.println();
	Serial.println("PillBox boot");

	pinMode(BUZZER_PIN, OUTPUT);
	pinMode(LID_SENSOR_PIN, INPUT_PULLUP);

	rtc.Begin();
	if (rtc.GetIsWriteProtected())
	{
		rtc.SetIsWriteProtected(false);
	}
	if (!rtc.GetIsRunning())
	{
		rtc.SetIsRunning(true);
	}

	// Создаем очередь для Telegram-сообщений (максимум 5 указателей на строки)
	msgQueue = xQueueCreate(5, sizeof(char *));

	// ЗАПУСК ПОТОКОВ
	// buzzerTask получает приоритет 3 (высокий), чтобы звук не прерывался
	xTaskCreate(buzzerTask, "BuzzerTask", 2048, nullptr, 3, nullptr);
	// Задачи отправки и приема сообщений получают приоритет 1 (фоновый) и по 10 КБ памяти стека
	xTaskCreate(telegramTask, "TelegramTask", 10240, nullptr, 1, nullptr);
	xTaskCreate(botPollTask, "BotPollTask", 10240, nullptr, 1, nullptr);

	// Загружаем сохраненные данные из памяти Flash
	prefs.begin("pillbox", true);
	ssid = prefs.getString("s", "");
	pass = prefs.getString("p", "");
	chatId = prefs.getString("c", "");
	alarm1 = prefs.getString("t1", "08:00");
	alarm2 = prefs.getString("t2", "20:00");
	prefs.end();

	if (ssid == "")
	{
		// Режим настройки (AP): запускаем свою сеть и Captive Portal
		Serial.println("WiFi settings are empty, starting setup portal.");
		startSetupPortal();
	}
	else
	{
		// Рабочий режим (STA): подключаемся к телефону
		Serial.print("Connecting to WiFi: ");
		Serial.println(ssid);
		WiFi.begin(ssid.c_str(), pass.c_str());
		int a = 0;
		while (WiFiClass::status() != WL_CONNECTED && a < 40)
		{
			delay(500);
			a++;
		}

		if (WiFiClass::status() == WL_CONNECTED)
		{
			Serial.print("WiFi connected, IP: ");
			Serial.println(WiFi.localIP());
			sendMsg("Таблетница в сети! 🟢");
		}
		else
		{
			// Если сохраненная сеть недоступна, поднимаем портал, чтобы можно было сразу перенастроить Wi-Fi.
			WiFi.disconnect(true);
			Serial.println("WiFi недоступен, запускаем портал настройки.");
			startSetupPortal();
		}
	}
}

void loop()
{
	serviceAlarm();
	serviceLidReset();

	if (WiFiClass::getMode() == WIFI_AP)
	{
		// Если мы в режиме настройки, отдаем веб-страницу пользователю
		dnsServer.processNextRequest();
		server.handleClient();
	}
	else
	{
		serviceWiFiReconnect();
	}
}

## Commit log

2026-05-07 feat: simple btn prototype
2026-06-03 feat: wire mode for a new build
2026-06-03 feat: stable wire build + fix buzzer's volume
    [main.cpp]
2026-06-03 docs: update stable wire build docs
